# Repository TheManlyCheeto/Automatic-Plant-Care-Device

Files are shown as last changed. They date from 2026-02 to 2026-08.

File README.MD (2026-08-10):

# Automatic Plant Care Device

**Senior Design Project — 2026**
**Authors:** Braeden Ewers & Tyson Limato

An autonomous, multi-plant care robot built by repurposing a **CoreXY 3D‑printer motion platform** into a gantry that drives across a 4‑plot grow bed, watering, lighting, imaging, and logging the health of each plant automatically. The whole system runs on **Klipper firmware + Moonraker** on a Raspberry Pi, with a custom sensor array, thermal camera, machine vision plot‑detection, and a purpose‑built LCD dashboard menu.

<p align="center">
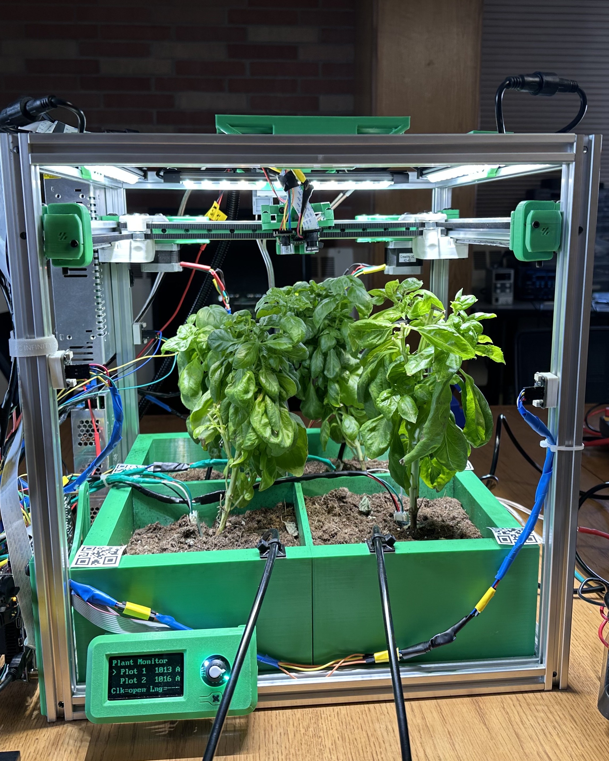
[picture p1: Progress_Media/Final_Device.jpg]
Complete Assembly
  
</p>

<p align="center">
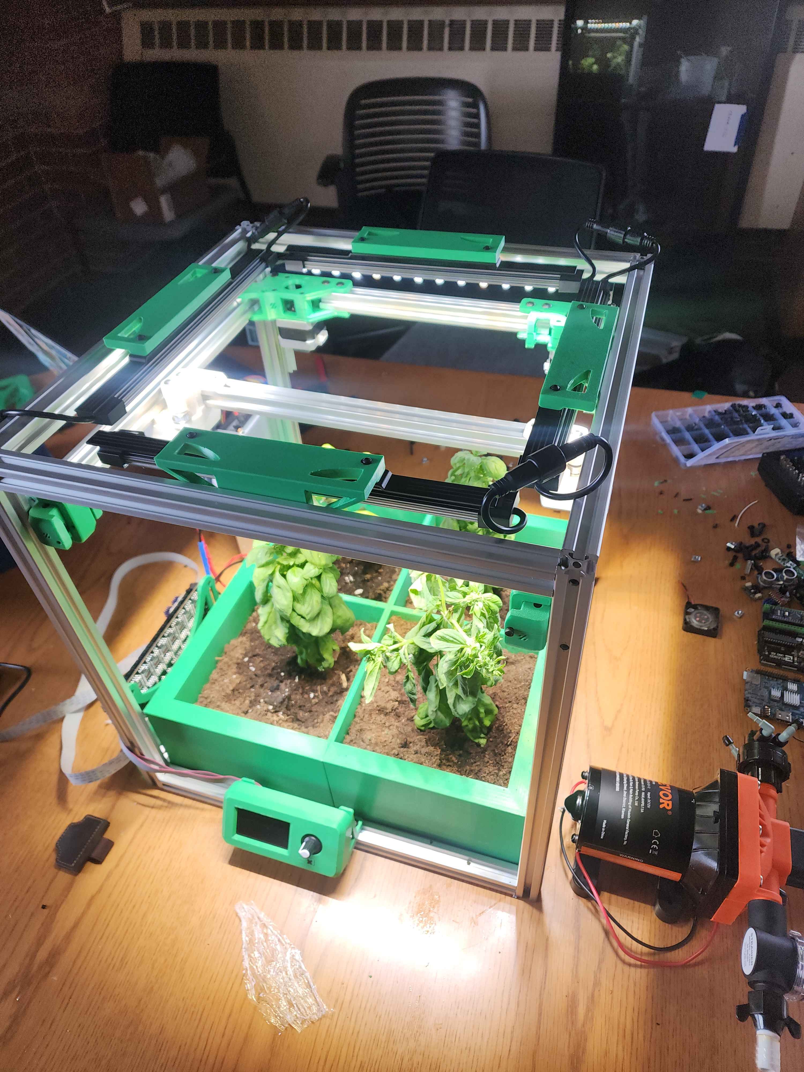
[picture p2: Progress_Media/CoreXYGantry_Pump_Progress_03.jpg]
CoreXY gantry and pump assembly
  
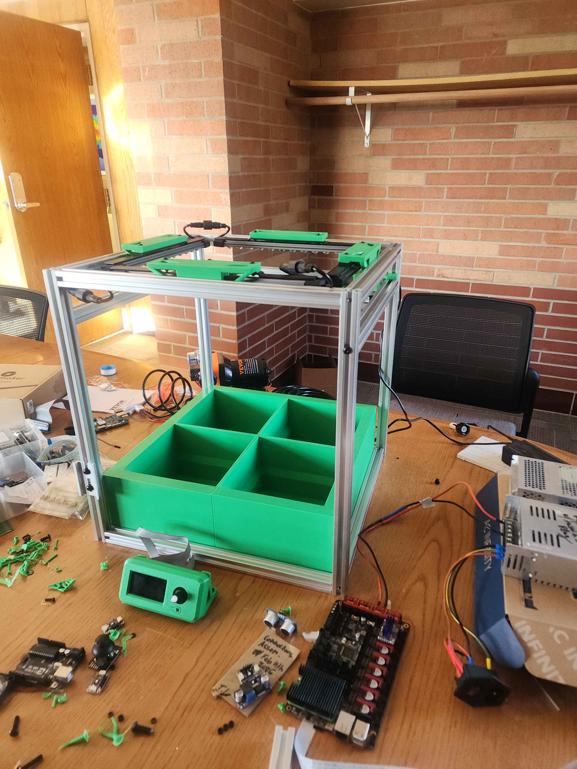
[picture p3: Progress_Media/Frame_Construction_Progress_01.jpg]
Frame construction
  
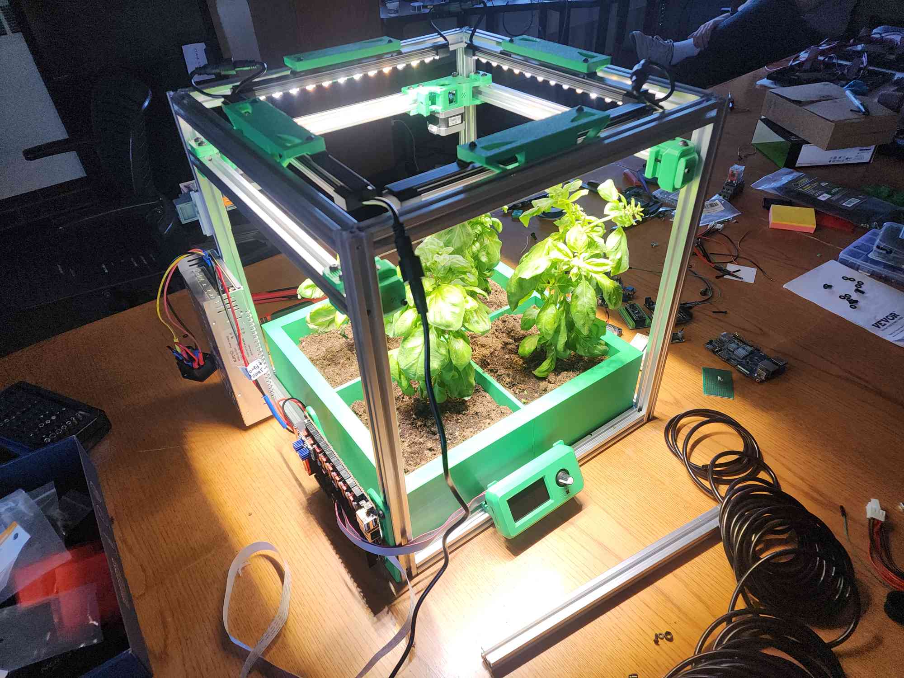
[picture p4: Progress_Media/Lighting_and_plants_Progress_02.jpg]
Grow lighting and plants
  
</p>

> Build/test clips also live in [`Progress_Media/`](./Progress_Media): `Gantry_Test_X_and_Y_Axis.mp4`, `Basic_Gantry_Test_Y_Axis.mp4`, `Pump_Test_1.mp4`, `Camera_Test_Light.mp4`, `Camera_Test_Dark.mp4`.

---

## Key Features

- **Autonomous multi-plot watering** — a solenoid/relay-driven pump is triggered through Klipper G-code macros (`PUMP_ON` / `PUMP_OFF`) on a timed schedule, with per-plant, per-plot watering cooldowns and thresholds.
- **Scheduled grow lighting** — lights automatically switch on/off daily (`LIGHT_ON` at 06:00, `LIGHT_OFF` at 18:00) via the same macro system.
- **4-plot environmental monitoring** — soil moisture, air temperature, and humidity are sampled continuously across four independent grow plots through a multiplexed I²C sensor bus.
- **Plant growth tracking** — an ultrasonic distance sensor measures canopy height over time to quantify plant growth.
- **Thermal imaging** — a 24×32 IR array camera renders a live false-color heat map of the plants/soil for stress and cold/hot-spot detection.
- **Computer-vision plot calibration** — a Pi camera + OpenCV pipeline detects a printed QR code and uses homography to project a real-world 162×162 mm bounding box onto the frame, anchoring the gantry's coordinate system to physical plot geometry.
- **CoreXY gantry motion** — the printer's X/Y motion system (driven through Moonraker's HTTP API) moves the toolhead across the bed to service each plot in sequence.
- **On-device LCD dashboard** — a custom Klipper display menu (`lcd_plants.py`) replaces the stock printer menu with a scrollable plant-monitor UI: per-plot readings, active alerts, editable moisture-warning thresholds, and quick-access commands (lights, pump, homing, motors off).
- **Per-plant configurable thresholds** — each plant type (e.g. `plants/basil.json`) defines its own acceptable soil, humidity, and temperature ranges, watering cooldown, and pump dose time.
- **JSON time-series logging** — every plot's minute-by-minute moisture/temperature/humidity/alert data is persisted to disk for later review or the LCD dashboard to read back.
- **3D-printed, purpose-built hardware** — nearly every structural and mounting part (idlers, tensioners, carriage plates, LCD mounts, sensor mounts) is custom-designed and printable from the included STL files.

---

## System Architecture

```
                 ┌─────────────────────────┐
                 │   Raspberry Pi (host)   │
                 │  Klipper + Moonraker    │
                 └───────────┬─────────────┘
                              │ HTTP (Moonraker API) / G-code macros
        ┌─────────────────────┼─────────────────────────┐
        │                     │                           │
 ┌──────▼──────┐     ┌────────▼────────┐       ┌──────────▼──────────┐
 │ CoreXY Gantry│     │  Pump & Lights  │       │  Mini12864 LCD Menu │
 │ (X/Y motion) │     │ (relay macros)  │       │   (lcd_plants.py)   │
 └──────────────┘     └─────────────────┘       └──────────────────────┘

 ┌───────────────────────────── Sensor Bus (I²C via TCA9548A mux) ─────────────────────────────┐
 │  Soil moisture ×4 (Seesaw, addr 0x36)     Air temp/humidity ×2 (AHTx0)                        │
 └────────────────────────────────────────────────────────────────────────────────────────────┘

 ┌───────────── Standalone GPIO / peripheral sensors ─────────────┐
 │  HC-SR04 ultrasonic (plant height)   MLX90640 thermal camera    │
 │  Pi Camera + OpenCV (QR/plot calibration)                        │
 └────────────────────────────────────────────────────────────────┘

 Python orchestration (system_demo.py) runs each subsystem as a
 separate process: watering/lighting scheduler, gantry movement,
 soil/air sensor polling + logging, and plant-growth reporting.
```

---

## Embedded Components & Hardware

| Component | Role | Notes |
|---|---|---|
| **Raspberry Pi** | Host controller | Runs Klipper's `klippy` host software, Moonraker API server, and all Python sensor/control scripts |
| **Klipper firmware + Moonraker** | Motion control backend | The project repurposes a 3D-printer's CoreXY motion system; watering/lighting/pump/homing are all issued as Klipper G-code macros over Moonraker's REST API |
| **CoreXY Gantry (repurposed 3D printer frame)** | X/Y positioning | Moves a toolhead across the 4-plot bed; custom-printed carriage mounts, idlers, and tensioners (see [`Plant_Device_STLs/`](./Plant_Device_STLs)) |
| **TCA9548A** | 8-channel I²C multiplexer | Fans out a single I²C bus to isolate 4 soil sensors + 2 air sensors that would otherwise share addresses |
| **Adafruit STEMMA Soil Sensor (Seesaw, addr `0x36`)** | Capacitive soil moisture + temperature | One per plot (4 total), read over the multiplexed I²C bus |
| **AHTx0 (AHT10/AHT20)** | Air temperature & relative humidity | 2 sensors, each shared across a pair of plots |
| **HC-SR04 ultrasonic distance sensor** | Plant growth / canopy height tracking | Wired with a resistor voltage divider on the echo line to safely interface with 3.3V GPIO; converts distance-to-canopy into a growth measurement |
| **MLX90640** | 24×32 pixel thermal IR camera | Streamed and upscaled (cubic interpolation) into a live `matplotlib` heat-map display for thermal monitoring |
| **Raspberry Pi Camera Module (Picamera2)** | Machine vision | Detects a printed QR code, computes a homography, and projects a known-size (162×162 mm) bounding box to calibrate plot position in the camera frame |
| **UC1701 "Mini12864" LCD (16×4 emulated)** | On-device dashboard | Custom Klipper display menu class (`PlantMenuManager`) with scrollable per-plot detail screens, an editable moisture-warning threshold, and a command menu (lights/pump/homing/motors off) |
| **Water pump** | Irrigation actuator | Fired through `PUMP_ON` / `PUMP_OFF` Klipper macros on a timed watering cycle |
| **Grow lights** | Lighting actuator | Fired through `LIGHT_ON` / `LIGHT_OFF` Klipper macros on a fixed daily schedule (06:00–18:00) |
| **3D-printed structural parts** | Mechanical frame | Custom Z-belt clamps, front idlers/tensioners, X-carriage frames, MGN9 rail/blocks, LCD T-bar mounts, and tool-head sensor/carriage mounts — all included as STL/F3D files |

---

## Software Stack

- **Klipper** — 3D-printer firmware repurposed purely for precise, reliable stepper-driven X/Y motion and macro-based I/O control.
- **Moonraker** — HTTP API layer used from Python (`urllib`) to send G-code moves and run macros remotely.
- **Python 3** (`multiprocessing`) — orchestrates concurrent subsystems: watering/lighting scheduler, gantry movement loop, soil/air sensor polling, and ultrasonic growth reporting (`system_demo.py`).
- **Adafruit CircuitPython libraries** — `adafruit_tca9548a`, `adafruit_ahtx0`, `adafruit_seesaw`, `adafruit_mlx90640` for sensor I/O over I²C.
- **OpenCV + NumPy** — QR detection, perspective/homography transforms for camera-based plot calibration.
- **Matplotlib + SciPy** — live-rendered, interpolated thermal camera visualization.
- **RPi.GPIO** — direct GPIO control for the ultrasonic sensor's trigger/echo lines.
- **JSON-based data logging** — per-plot, per-minute summaries (avg/min/max moisture, humidity, temperature, watering recommendations, active alerts) written to `logs/`.
- **Per-plant config files** (`plants/*.json`) — declarative soil/humidity/temperature thresholds, watering cooldown, and pump dose time per plant species (e.g. `basil.json`).
- **Conda environment** (`environment_droplet.yml`) — reproducible environment for the computer-vision stack (OpenCV, FFmpeg, etc.).

---

## Repository Structure

```
Automatic-Plant-Care-Device/
├── Plant_Device_STLs/        # 3D-printable CAD parts (gantry, mounts, idlers, LCD brackets)
├── Progress_Media/           # Build photos & test videos
├── logs/                     # Per-plot, per-day JSON sensor logs
├── plants/                   # Per-plant threshold configs (e.g. basil.json)
├── scripts/                  # Helper/setup scripts (e.g. update_environment_yml.sh)
├── std_vis/                  # Vision-related assets
├── system_demo.py            # Main orchestrator: watering/lighting, gantry, sensors, growth
├── TestTogether.py           # Combined soil + air sensor polling & JSON logging
├── DatabaseMainTest.py       # Per-plant threshold checking logic
├── Humidity.py               # Standalone AHTx0 sensor test
├── MultiplexorTest.py        # TCA9548A channel scan/test
├── Soili2cTest.py            # Standalone soil sensor test
├── ThermalDisplay.py         # Live MLX90640 thermal camera viewer
├── ThermalTest.py            # Thermal sensor test
├── ultrasonic_sensor.py      # HC-SR04 distance / plant-growth measurement
├── std_vis.py                # Pi Camera + OpenCV QR-based plot calibration
├── lcd_plants.py             # Custom Klipper LCD menu (plant dashboard)
└── environment_droplet.yml   # Conda environment for the CV stack
```

---

## Getting Started

> This project assumes a Klipper-controlled CoreXY frame (built from the included STL parts) with a Raspberry Pi running Klippy + Moonraker.

1. **Build the frame** — 3D-print the parts in [`Plant_Device_STLs/`](./Plant_Device_STLs) and assemble the CoreXY gantry, mounting the toolhead, LCD bracket, and sensor mounts.
2. **Flash & configure Klipper/Moonraker** on the Raspberry Pi, and add `PUMP_ON`, `PUMP_OFF`, `LIGHT_ON`, `LIGHT_OFF`, `HOME_XY`, and `CENTER` macros to `printer.cfg`.
3. **Install the LCD dashboard** — copy `lcd_plants.py` into `~/klipper/klippy/extras/display/`, and add a `[lcd_plants]` section to `printer.cfg` with your `log_dir` and `plant_name`.
4. **Wire up the sensors** — soil sensors + AHTx0 sensors through the TCA9548A multiplexer, HC-SR04 to GPIO 5 (trig) / GPIO 24 (echo, with a voltage divider), MLX90640 over I²C, and the Pi Camera to the CSI port.
5. **Set up the Python environment**:
   ```bash
   conda env create -f environment_droplet.yml
   conda activate cv
   pip install adafruit-circuitpython-tca9548a adafruit-circuitpython-ahtx0 adafruit-circuitpython-seesaw adafruit-circuitpython-mlx90640 RPi.GPIO
   ```
6. **Configure your plant(s)** — add/edit a JSON file in `plants/` (see `basil.json`) with soil/humidity/temperature ranges, watering cooldown, and pump dose time.
7. **Run the system**:
   ```bash
   python3 system_demo.py
   ```
   This starts the watering/lighting scheduler, gantry movement loop, soil/air sensor logger, and ultrasonic growth tracker as parallel processes.

---

## Media

| | |
|---|---|
| Frame construction | Frame construction — the CoreXY chassis being assembled from printed and rail hardware. |
| Lighting and plants | Grow lighting installed above the live plot bed. |
| Gantry and pump | CoreXY gantry with the watering pump mounted and integrated. |

Additional test footage (gantry motion, pump actuation, and camera performance in light/dark conditions) is available in [`Progress_Media/`](./Progress_Media).

---

## Authors

Built by **Braeden Ewers** and **Tyson Limato** as a Senior Design capstone project (2026).

---

## License

No license file is currently included in the repository — check with the authors before reuse or redistribution.

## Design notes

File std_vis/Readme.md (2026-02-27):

References to Expand the computer vision component for QR Bounding boxes

1) https://docs.opencv.org/4.x/de/dc3/classcv_1_1QRCodeDetector.html?utm_source=chatgpt.com
2) https://docs.opencv.org/3.4/de/dc3/classcv_1_1QRCodeDetector.html?utm_source=chatgpt.com
3) https://learnopencv.com/opencv-qr-code-scanner-c-and-python/?utm_source=chatgpt.com

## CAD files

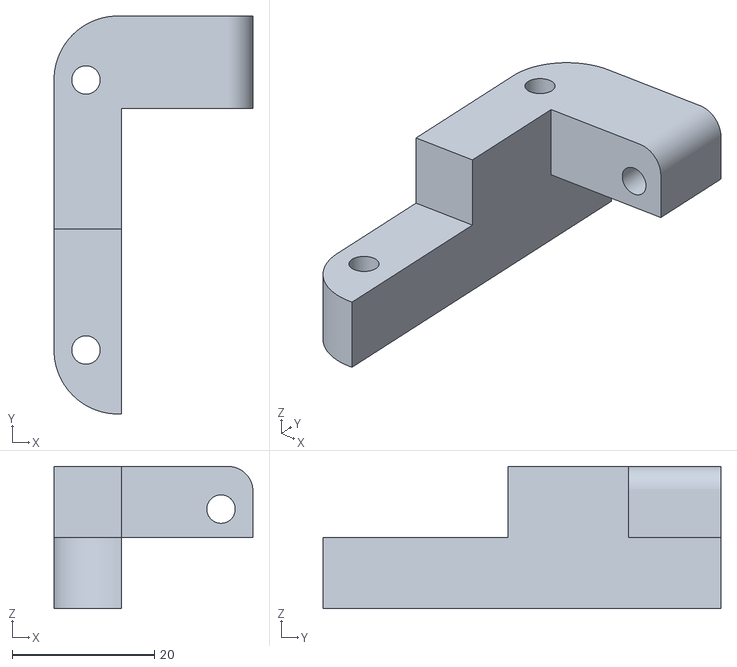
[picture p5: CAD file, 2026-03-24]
Plant_Device_STLs/ToolHeadLeftCarriageMount.stl
28.0 x 56.0 x 20.0

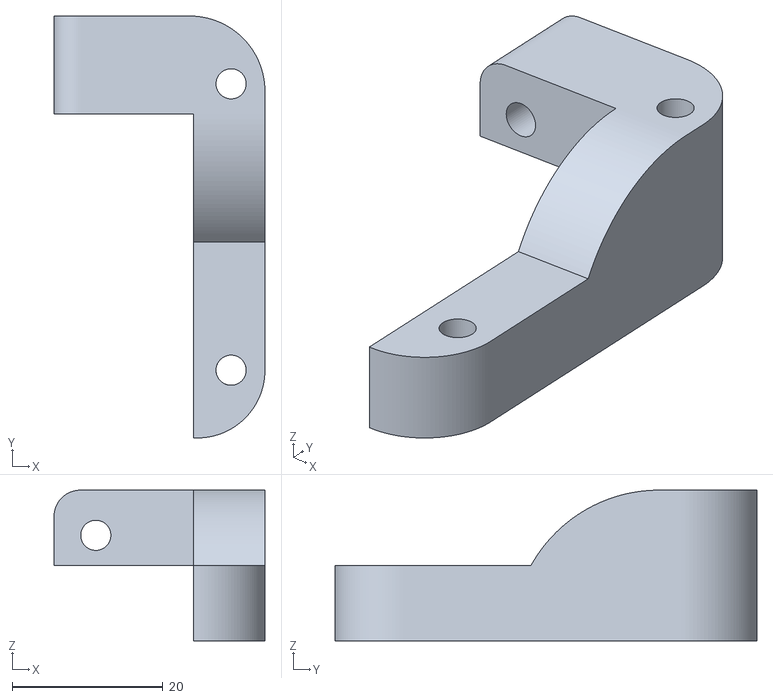
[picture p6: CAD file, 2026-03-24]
Plant_Device_STLs/Toolheadrightcarriagemount.stl
28.0 x 56.0 x 20.0

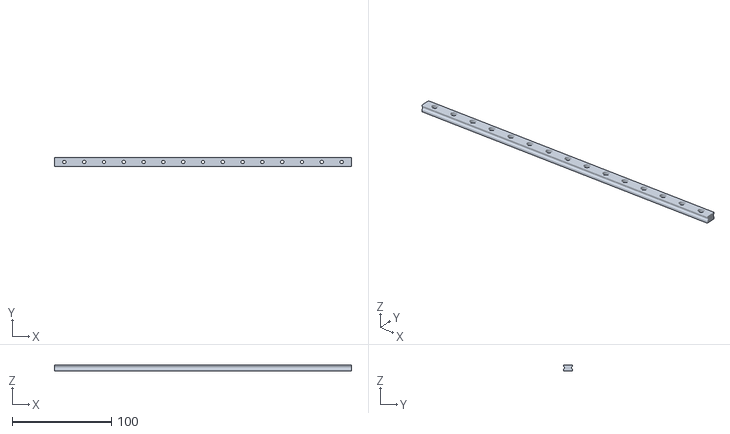
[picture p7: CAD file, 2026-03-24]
Plant_Device_STLs/mgn9_y_rail.stl
300.0 x 9.00 x 6.50

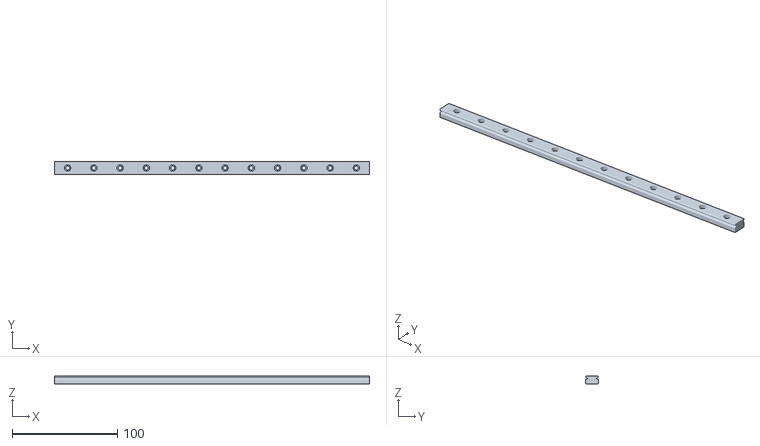
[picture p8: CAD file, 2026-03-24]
Plant_Device_STLs/mid rail.stl
300.0 x 12.0 x 8.00

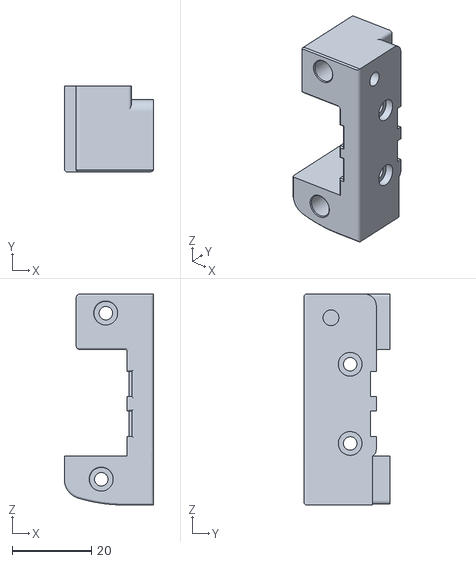
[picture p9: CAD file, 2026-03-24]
Plant_Device_STLs/x_carriage_frame_left.stl
22.6 x 21.6 x 53.3

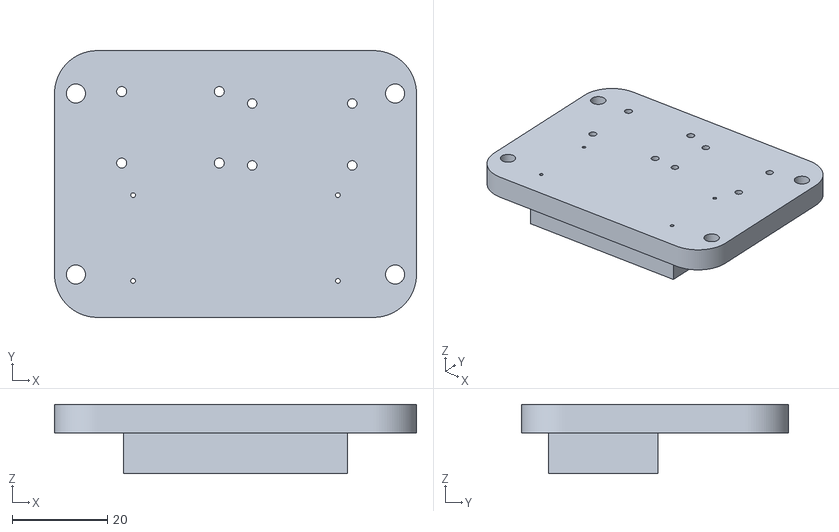
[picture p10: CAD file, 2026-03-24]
Plant_Device_STLs/ToolHeadSensorMount.stl
76.0 x 56.0 x 14.5

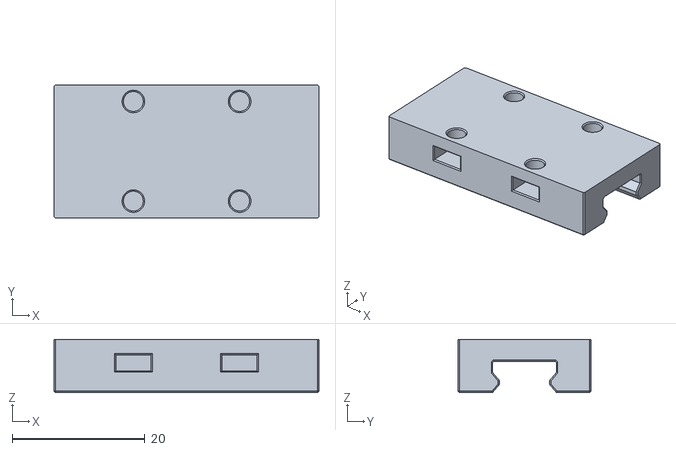
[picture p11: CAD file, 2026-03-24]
Plant_Device_STLs/mgn9_Y_block.stl
39.9 x 20.0 x 8.00

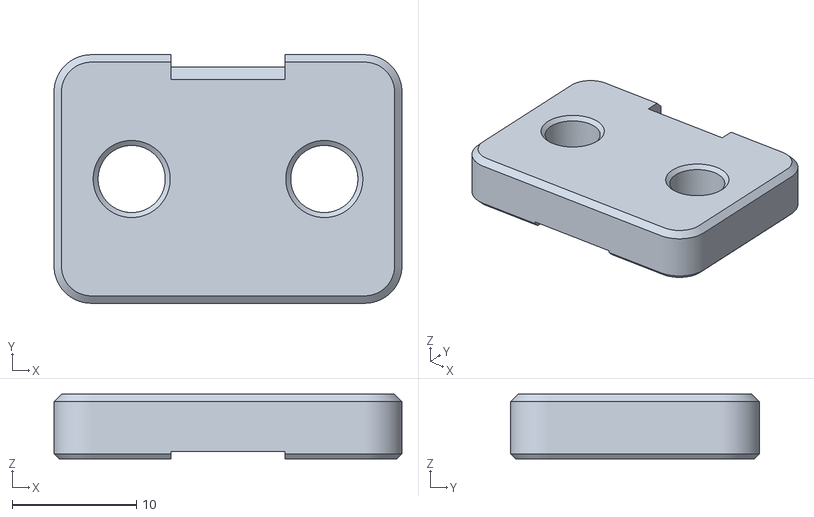
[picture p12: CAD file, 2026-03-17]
Plant_Device_STLs/A Front Idler Z tension.stl
28.0 x 20.0 x 5.20

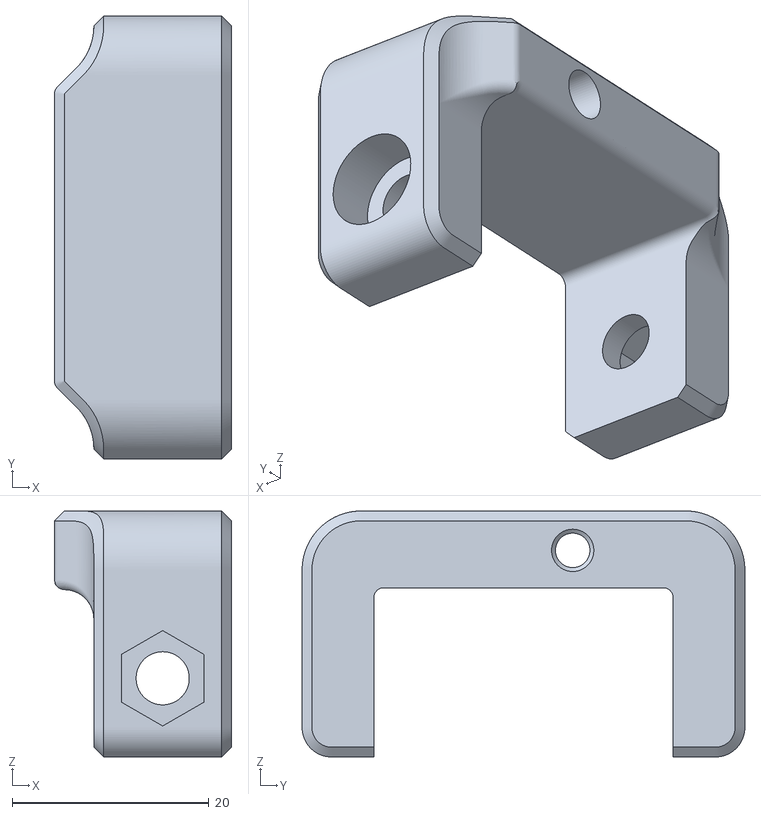
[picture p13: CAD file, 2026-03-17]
Plant_Device_STLs/A Front Tensioner.stl
18.0 x 45.0 x 25.0

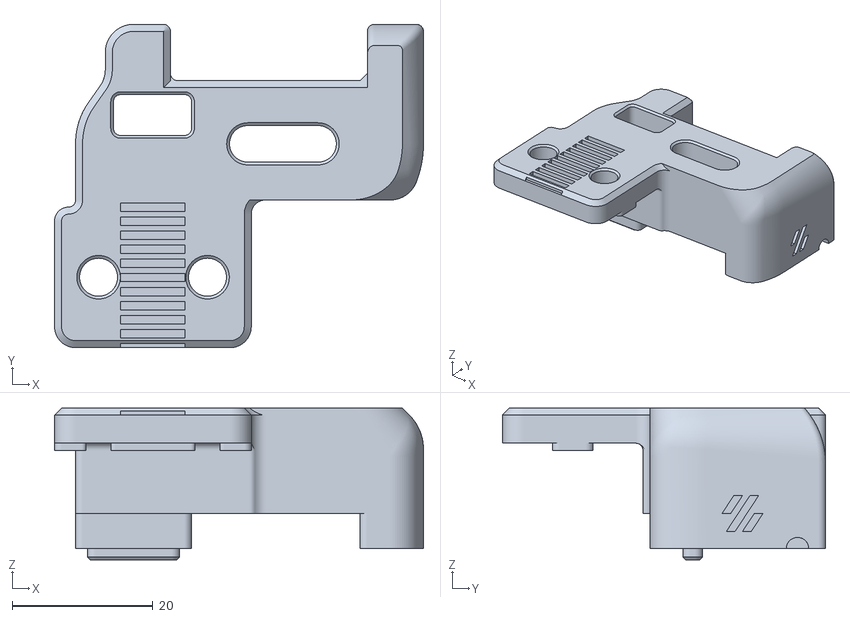
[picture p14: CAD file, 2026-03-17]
Plant_Device_STLs/B Front Idler Top.stl
52.5 x 46.0 x 21.6

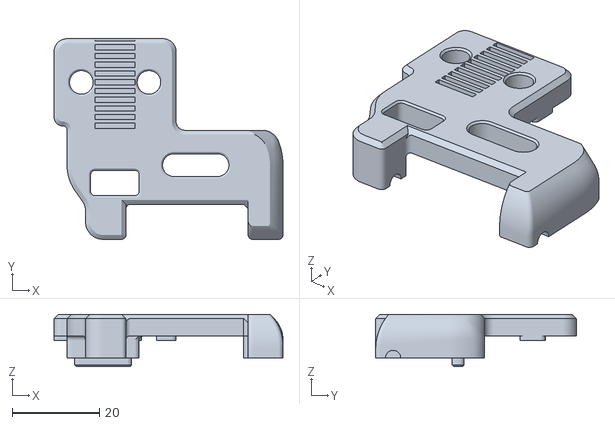
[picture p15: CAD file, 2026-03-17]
Plant_Device_STLs/A Front Idler Top.stl
52.5 x 46.0 x 12.0

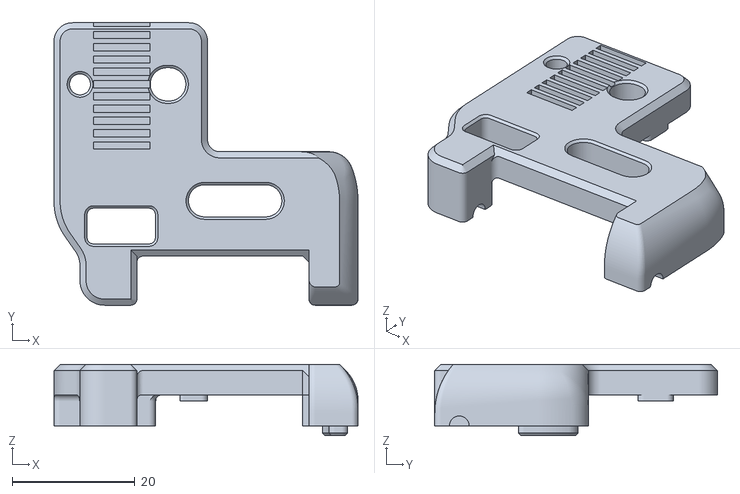
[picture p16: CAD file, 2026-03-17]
Plant_Device_STLs/B Front Idler Bottom.stl
49.5 x 46.0 x 11.6

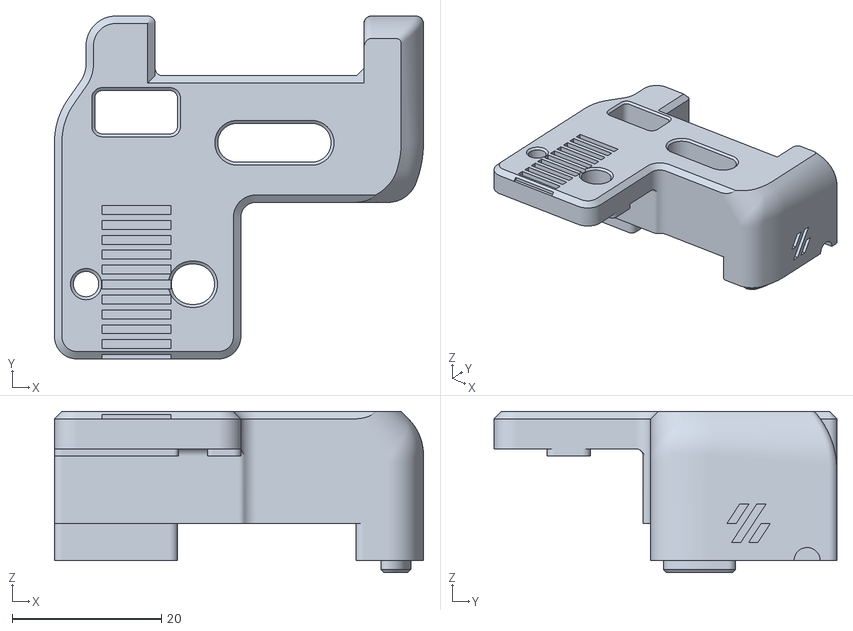
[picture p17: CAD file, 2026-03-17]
Plant_Device_STLs/A Front Idler Bottom.stl
49.5 x 46.0 x 21.6

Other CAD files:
Plant_Device_STLs/x_carriage_frame_right.stl
Plant_Device_STLs/B Drive Z Clamp.stl
Plant_Device_STLs/Front Idler Z Clamp B.stl
Plant_Device_STLs/B tensioner.stl
Plant_Device_STLs/Light Mounts v3 Increased Clearance.stl
Plant_Device_STLs/Mantam8p_mount_V3_shifted_m5bolts.stl
Plant_Device_STLs/Mounting Bridge.stl
Plant_Device_STLs/left_lcd_Tbar_mount_plate v2.stl
Plant_Device_STLs/mid rail carriage holder.f3d
Plant_Device_STLs/right_lcd_Tbar_mount_plate v1.stl
Plant_Device_STLs/screen_frame_additional_Mountpoint.stl

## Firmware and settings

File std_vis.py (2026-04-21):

import cv2 as cv
import numpy as np
import time
from picamera2 import Picamera2

W, H = 640, 480

# -----------------------------
# Physical dimensions in mm
# -----------------------------
QR_SIZE_MM = 31     #SOLVED: CHANGE THIS to the actual printed QR size I SWEAR TO GOD TYSON YOU BASTARD MAN
BOX_SIZE_MM = 162.0    # desired box size

# -----------------------------
# Picamera2 setup
# -----------------------------
picam2 = Picamera2()
config = picam2.create_preview_configuration(
    main={"format": "BGR888", "size": (W, H)}
)
picam2.configure(config)
picam2.start()
time.sleep(1)

# -----------------------------
# OpenCV setup
# -----------------------------
source_window = "QR Box"
cv.namedWindow(source_window)

qr_detector = cv.QRCodeDetector()

def draw_labeled_polygon(img, pts, color, label=None, thickness=2):
    pts_int = pts.astype(np.int32).reshape((-1, 1, 2))
    cv.polylines(img, [pts_int], True, color, thickness)

    if label is not None:
        x, y = pts_int[0, 0]
        cv.putText(
            img,
            label,
            (x + 8, y - 8),
            cv.FONT_HERSHEY_SIMPLEX,
            0.6,
            color,
            2,
            cv.LINE_AA
        )

while True:
    frame = picam2.capture_array()
    frame = cv.flip(frame, -1) # then flip 180 degrees (accross horizontal line)
    display = frame.copy()

    retval, decoded_info, points, _ = qr_detector.detectAndDecodeMulti(frame)

    if retval and points is not None:
        for i, qr_pts in enumerate(points):
            img_pts = np.array(qr_pts, dtype=np.float32)

            # Draw detected QR outline
            draw_labeled_polygon(display, img_pts, (0, 255, 0), "QR")

            # Read and display decoded QR value
            qr_text = decoded_info[i] if i < len(decoded_info) else ""
            if qr_text:
                tx, ty = img_pts[0].astype(int)
                cv.putText(
                    display,
                    f"Data: {qr_text}",
                    (tx + 8, ty + 20),
                    cv.FONT_HERSHEY_SIMPLEX,
                    0.5,
                    (0, 255, 0),
                    2,
                    cv.LINE_AA
                )
                print(f"QR decoded: {qr_text}")

            # -----------------------------------------
            # QR real-world coordinates in mm
            # top-left, top-right, bottom-right, bottom-left
            # -----------------------------------------
            world_qr = np.array([
                [0.0, 0.0],
                [QR_SIZE_MM, 0.0],
                [QR_SIZE_MM, QR_SIZE_MM],
                [0.0, QR_SIZE_MM]
            ], dtype=np.float32)

            # Homography from mm plane -> image
            H_mat = cv.getPerspectiveTransform(world_qr, img_pts)

            # -----------------------------------------
            # 162 mm x 162 mm box
            # QR is the BOTTOM-RIGHT corner of the box
            #
            # So the box extends:
            #   left by BOX_SIZE_MM from QR left edge
            #   up by BOX_SIZE_MM from QR bottom edge
            #
            # In world coordinates:
            #   QR occupies x: [0, QR_SIZE_MM], y: [0, QR_SIZE_MM]
            #   Box bottom-right aligns with QR bottom-right: (QR_SIZE_MM, QR_SIZE_MM)
            #   Box extends left and up by BOX_SIZE_MM
            # -----------------------------------------
            world_box = np.array([
                [QR_SIZE_MM - BOX_SIZE_MM, QR_SIZE_MM - BOX_SIZE_MM],   # top-left of box
                [QR_SIZE_MM,               QR_SIZE_MM - BOX_SIZE_MM],   # top-right of box
                [QR_SIZE_MM,               QR_SIZE_MM],                  # bottom-right = QR bottom-right
                [QR_SIZE_MM - BOX_SIZE_MM, QR_SIZE_MM]                  # bottom-left of box
            ], dtype=np.float32).reshape(-1, 1, 2)

            img_box = cv.perspectiveTransform(world_box, H_mat).reshape(-1, 2)

            # Draw projected 162x162 mm box
            draw_labeled_polygon(display, img_box, (255, 0, 255), "162mm x 162mm")

            # Mark anchor at QR bottom-right
            anchor_world = np.array([[[QR_SIZE_MM, QR_SIZE_MM]]], dtype=np.float32)
            anchor_img = cv.perspectiveTransform(anchor_world, H_mat).reshape(2)
            anchor = tuple(anchor_img.astype(int))

            cv.circle(display, anchor, 5, (0, 0, 255), -1)
            cv.putText(
                display,
                "Anchor: QR bottom-right",
                (anchor[0] + 8, anchor[1] - 8),
                cv.FONT_HERSHEY_SIMPLEX,
                0.5,
                (0, 0, 255),
                2,
                cv.LINE_AA
            )

    else:
        cv.putText(
            display,
            "No QR detected",
            (20, 30),
            cv.FONT_HERSHEY_SIMPLEX,
            0.8,
            (0, 0, 255),
            2,
            cv.LINE_AA
        )

    cv.imshow(source_window, display)

    key = cv.waitKey(1) & 0xFF
    if key == ord('q') or key == 27:
        break

picam2.stop()
cv.destroyAllWindows()

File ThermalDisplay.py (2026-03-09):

import time
import numpy as np
import matplotlib.pyplot as plt
from scipy.ndimage import zoom

import board
import busio
import adafruit_mlx90640

ROWS, COLS = 24, 32
UPSCALE = 10          # 24x32 → 240x320 
VMIN = 20             #°C lower bound (adjust)
VMAX = 35              #°C upper bound (adjust)

i2c = busio.I2C(board.SCL, board.SDA, frequency=800000)
mlx = adafruit_mlx90640.MLX90640(i2c)
mlx.refresh_rate = adafruit_mlx90640.RefreshRate.REFRESH_2_HZ

frame = [0.0] * (ROWS * COLS)

plt.ion()
fig, ax = plt.subplots()
fig.canvas.manager.set_window_title("MLXHeatCam")

img = ax.imshow(
    np.zeros((ROWS*UPSCALE, COLS*UPSCALE)),
    cmap="plasma",      
    vmin=VMIN,
    vmax=VMAX
)

ax.axis("off")
cbar = plt.colorbar(img, ax=ax, fraction=0.046)
cbar.set_label("Temperature (°C)")

while True:
    try:
        mlx.getFrame(frame)

        data = np.array(frame).reshape((ROWS, COLS))

       
        data = np.flipud(data)

        # Smooth upscale
        data_up = zoom(data, UPSCALE, order=3)  # cubic interpolation

        img.set_data(data_up)
        ax.set_title(
            f"Min {data.min():.1f}°C | Max {data.max():.1f}°C",
            color="white"
        )

        plt.pause(0.001)

    except ValueError:
        pass

    time.sleep(0.05)

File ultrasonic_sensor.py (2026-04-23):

import RPi.GPIO as GPIO
import time
# Voltage Divider on the Echo pin.
# ECHO pin -> 1kohm -> GPIO 24 -> 2kohm -> GND

TRIG_PIN = 5
ECHO_PIN = 24

GPIO.setmode(GPIO.BCM)
GPIO.setup(TRIG_PIN, GPIO.OUT)
GPIO.setup(ECHO_PIN, GPIO.IN)

def measure_distance() -> float:
    # Send trigger pulse
    GPIO.output(TRIG_PIN, False)
    time.sleep(0.002)  # let sensor settle (buffer for prop delay)

    GPIO.output(TRIG_PIN, True)
    time.sleep(0.00001)  # 10us pulse
    GPIO.output(TRIG_PIN, False)

    # Wait for echo to start
    timeout = time.time() + 8
    pulse_start = time.time()
    while GPIO.input(ECHO_PIN) == 0:
        pulse_start = time.time()
        if time.time() > timeout:
            print("Timeout waiting for echo start")
            GPIO.cleanup()
            exit()

    # Wait for echo to end
    pulse_end = time.time()
    while GPIO.input(ECHO_PIN) == 1:
        #print("Wait for echo to end")
        pulse_end = time.time()

    # Calculate distance
    pulse_duration = pulse_end - pulse_start
    distance = (pulse_duration * 34300) / 2  # speed of sound in cm/s
    print(f"distance: {distance}")
    return round(distance, 2)

def report_plant_growth():
    try:
        print("while is running")
        while True:
            dist = measure_distance()
            plant_growth = 245.3 - dist # distance from ultrasonic sensor to the dirt level
            print(f"Distance: {dist} mm, Plant Growth: {plant_growth} mm")
            time.sleep(5)

    except KeyboardInterrupt:
        print("Stopped")
        GPIO.cleanup()

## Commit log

2026-02-27 conda_env_v1 + CAD stl model uploads
    [Light Mounts v3 Increased Clearance.stl, Mantam8p_mount_V3_shifted_m5bolts.stl, Mounting Bridge.stl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]
2026-02-27 add soil sensor test scipt
2026-02-27 Thermal Camera Working
2026-02-27 show camera Results
2026-03-11 Front Idlers and Z Clamps for CoreXY motion System
    [A Drive Z Belt Clamp.stl, A Front Idler Bottom.stl, A Front Idler Top.stl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]
2026-03-17 file for i2c with soil sensor
2026-03-19 Functional database and main function for sensors
2026-03-24 Additional CAD Files
    [ToolHeadLeftCarriageMount.stl, ToolHeadSensorMount.stl, Toolheadrightcarriagemount.stl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]
2026-04-18 updated camera config
2026-04-21 ultrasonic sensor
2026-04-21 redesigned UI for 16x4 style display
    [lcd_plants.py]
2026-04-21 now run directly by display.py in klipper
2026-04-21 corrected channels for SPI soil sense
    [TestTogether.py]
2026-04-22 added plots and ultrasonic sensor test
2026-04-22 testing code + functional ultrasonic
2026-08-10 Better Pictures of the Final Device
2026-08-10 Rename Final Device.jpg to Final_Device.jpg
